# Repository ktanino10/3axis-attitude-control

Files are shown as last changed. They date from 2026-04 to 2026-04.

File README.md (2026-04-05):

# 🎲 3軸姿勢制御モジュール（Self-Balancing Cube）

> 🇬🇧 [English version here (README_en.md)](README_en.md)

リアクションホイールを用いた3軸姿勢制御モジュールの制作記録です。  
立方体が **角（頂点）で自立する** 倒立振子ロボットを、GitHub Copilot CLI を活用しながら設計・実装していきます。

## 🎯 プロジェクト概要

<div align="center">

**立方体が角で立つ？！**  
3つのリアクションホイールで Roll / Pitch / Yaw の3軸を制御し、  
不安定な頂点倒立を実現します。

</div>

## 📖 ドキュメント

| # | ドキュメント | 内容 |
|---|---|---|
| 1 | [理論解説](docs/01_theory.md) | なぜ角で立てるのか？数式による物理的説明 |
| 2 | [部品表（BOM）](docs/02_bom.md) | 必要な部品・購入先リスト |
| 3 | [回路図・配線](docs/03_circuit.md) | 回路図、ピン配線表 |
| 4 | [ソフトウェア環境](docs/04_software_setup.md) | Arduino IDE / Processing IDE セットアップ |
| 5 | [組立手順](docs/05_assembly.md) | 機械・電気の組立ガイド |
| 6 | [チューニング](docs/06_tuning.md) | PIDパラメータ調整方法 |
| 📅 | [実験スケジュール](docs/schedule.md) | 工程表・進捗管理 |
| 📝 | [実験ログ](experiments/log.md) | 日々の実験記録 |

## 🔧 ハードウェア構成

| コンポーネント | 型番・仕様 |
|---|---|
| マイコン | Raspberry Pi Pico W / ESP32 |
| IMU | MPU6050（6軸加速度・ジャイロ） |
| モーター | Nidec 24H055M020（ドライバ内蔵BLDC）×3 |
| リアクションホイール | 3Dプリント製 Φ116mm ×3 |
| バッテリー | LiPo 3S 11.1V |
| 筐体 | 3Dプリント製（PLA）□136mm |

## 📁 リポジトリ構成

```
├── docs/              # ドキュメント（理論・BOM・回路図・手順書）
├── firmware/          # マイコンファームウェア
│   ├── pico_w/       # Raspberry Pi Pico W 版
│   └── esp32/        # ESP32 版
├── processing/        # PIDチューニングGUI（Processing）
├── hardware/          # 回路図・ガーバーデータ
│   ├── gerber/
│   └── schematics/
└── experiments/       # 実験ログ
```

## 🙏 謝辞・参考

- [imo Lab.](https://garchiving.com/summary-of-self-balancing-cube/) — 設計の参考にさせていただきました
- [remrc/Self-Balancing-Cube](https://github.com/remrc/Self-Balancing-Cube)
- [willem-pennings/balancing-cube](https://github.com/willem-pennings/balancing-cube)
- 制作には [GitHub Copilot CLI](https://github.com/features/copilot) を活用しています

## 📄 ライセンス

MIT License

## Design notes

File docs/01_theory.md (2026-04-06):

# 🎲 3軸姿勢制御の物理理論

> なぜ立方体が角（頂点）で立てるのか？数式を用いた理論的解説

---

## 目次

1. [はじめに](#1-はじめに)
2. [このプロジェクトで使われる学問分野](#2-このプロジェクトで使われる学問分野)
3. [3次元倒立振子モデル](#3-3次元倒立振子モデル)
4. [リアクションホイールの原理](#4-リアクションホイールの原理)
5. [運動方程式の導出](#5-運動方程式の導出)
6. [座標系とキューブの幾何学](#6-座標系とキューブの幾何学)
7. [PID制御理論](#7-pid制御理論)
8. [モーターミキシング](#8-モーターミキシング)
9. [姿勢推定アルゴリズム](#9-姿勢推定アルゴリズム)
10. [安定条件の考察](#10-安定条件の考察)
11. [まとめ](#11-まとめ)

---

## 1. はじめに

立方体を角（頂点）の上に立てる — 直感的には不可能に思える。しかし、**リアクションホイール** と **フィードバック制御** を組み合わせれば、この不安定な平衡状態を維持できる。

本ドキュメントでは、この物理現象を数式で説明する。

### 1.1 本プロジェクトの物理的本質

角に立つ立方体は、本質的に **3次元倒立振子（3D Inverted Pendulum）** である。

- 🔴 **不安定平衡**: 重心が支点（角）の **真上** にあるとき、力学的には平衡状態だが、微小な擾乱で倒れ始める
- 🟢 **能動的安定化**: 3つのリアクションホイールが **角運動量の交換** によりトルクを発生させ、倒れを修正する
- 🔵 **フィードバック制御**: IMUセンサで傾きを検出し、PID制御で適切なモータートルクを計算する

### 1.2 身近な例で理解する

この原理は実は身近なところでも使われている:

| 身近な例 | 共通する原理 |
|---|---|
| **自転車に乗る人** | 傾きを感じたらハンドルを切って修正 → フィードバック制御 |
| **フィギュアスケートのスピン** | 腕を縮めると回転が速くなる → 角運動量保存則 |
| **人工衛星の姿勢制御** | リアクションホイールで向きを変える → 本プロジェクトと同じ原理！ |
| **セグウェイ** | 2輪で倒立する → 1軸の倒立振子 |

> 💡 実は人工衛星と同じ技術を手のひらサイズで実現するのがこのプロジェクトの面白さ。
> NASAの宇宙船もリアクションホイールで姿勢制御している。

### 1.3 なぜ「角」は特別なのか

通常の立方体の安定姿勢は **面** の上に置いた状態。角で立てることは物理的に可能だが、
**静的には不安定** である。

安定性の種類を整理すると:

```
安定平衡（面の上）     不安定平衡（角の上）     中立平衡（球）
     ___                    ●                      ○
    /   \                  / \                 ─────────
   /  ●  \               /   \
  / 谷底  \             / 山頂 \              どこでも平衡
```

- **安定平衡**: ボールが谷底にある状態。少し動かしても戻る
- **不安定平衡**: ボールが山頂にある状態。少し動かすと転がり落ちる ← **今回はここ！**
- **中立平衡**: 平面上のボール。動いたらその場にとどまる

角の上に立つ立方体は「山頂のボール」と同じ不安定平衡状態。
**常に能動的にバランスを取り続けなければ倒れる。**

---

## 2. このプロジェクトで使われる学問分野

このプロジェクトは一つの分野だけでは完成しない。
複数の学問が組み合わさった **メカトロニクス（ロボティクス）** の典型例である。

### 2.1 学問分野マップ

```
┌─────────────────────────────────────────────────────────────┐
│                  3軸姿勢制御モジュール                       │
│                                                             │
│  ┌──────────┐  ┌──────────┐  ┌──────────┐  ┌──────────┐   │
│  │ 物理学   │  │ 数学     │  │制御工学  │  │電気電子  │   │
│  │          │  │          │  │          │  │工学      │   │
│  │・古典力学│  │・線形代数│  │・PID制御 │  │・回路設計│   │
│  │・剛体力学│  │・微分方程│  │・状態空間│  │・モーター│   │
│  │・角運動量│  │  式      │  │  表現    │  │  制御    │   │
│  │  保存則  │  │・三角関数│  │・ディジタ│  │・センサ  │   │
│  │          │  │・テイラー│  │  ル信号  │  │  工学    │   │
│  │          │  │  展開    │  │  処理    │  │・PWM     │   │
│  └──────────┘  └──────────┘  └──────────┘  └──────────┘   │
│                                                             │
│  ┌──────────┐  ┌──────────┐  ┌──────────┐                  │
│  │ 情報工学 │  │ 機械工学 │  │通信工学  │                  │
│  │          │  │          │  │          │                  │
│  │・組込み  │  │・3D CAD  │  │・Bluetooth│                 │
│  │  プログラ│  │・3Dプリン│  │・シリアル│                  │
│  │  ミング  │  │  ト      │  │  通信    │                  │
│  │・I2C通信 │  │・機構設計│  │          │                  │
│  │・割り込み│  │・重心設計│  │          │                  │
│  └──────────┘  └──────────┘  └──────────┘                  │
└─────────────────────────────────────────────────────────────┘
```

### 2.2 各分野の詳細と本プロジェクトでの使われ方

#### 🔬 物理学（古典力学・剛体の力学）

最も基礎となる分野。「なぜ角で立てるのか」の答えそのもの。

| 物理法則 | 本プロジェクトでの使い方 | 登場する章 |
|---|---|---|
| **ニュートンの運動法則** | 回転版（$\tau = I\alpha$）で運動方程式を立てる | 第5章 |
| **角運動量保存則** | ホイールを加速→本体に逆トルク発生 | 第4章 |
| **重力トルク** | $mgl\sin\theta$ — 倒そうとする力 | 第5章 |
| **慣性モーメント** | $I = \frac{1}{6}ma^2$ — 回転のしにくさ | 第3章 |

> 📚 **学ぶなら**: 大学物理学（力学）、解析力学の教科書

#### 📐 数学

物理現象を定量的に扱うための道具。

| 数学の道具 | 何に使うか | 具体例 |
|---|---|---|
| **微分方程式** | 運動方程式の記述・解析 | $I\ddot{\theta} = mgl\theta - \tau$ |
| **線形代数** | ミキシング行列、状態空間表現 | 3×2のモーター分配行列 |
| **三角関数** | モーター配置の幾何学 | $\cos 30° = 0.866$ |
| **テイラー展開** | 小角近似 | $\sin\theta \approx \theta$ |
| **指数関数** | 不安定系の発散の記述 | $\theta(t) = \theta\_0 e^{\lambda t}$ |
| **atan2関数** | 加速度から角度を算出 | $\theta = \text{atan2}(a\_y, a\_z)$ |

> 📚 **学ぶなら**: 微分積分学、線形代数、工業数学

#### 🤖 制御工学

不安定な系を安定化させる理論。本プロジェクトの**要（かなめ）**。

| 制御理論 | 何をするか | ひとことで |
|---|---|---|
| **フィードバック制御** | センサで測定→計算→モーター駆動を繰り返す | 「測って→考えて→動く」のループ |
| **PID制御** | 偏差に対して比例・積分・微分の3つで修正 | 最も広く使われる基本制御器 |
| **安定性解析** | 系が発散しないか数学的に判定 | 固有値が正→不安定 |
| **離散化** | 連続系をデジタル（マイコン）で実装 | 10msごとにサンプリング |
| **相補フィルタ** | 2つのセンサの長所を組み合わせる | ジャイロ（速い）+ 加速度（正確） |

> 📚 **学ぶなら**: 制御工学入門、現代制御理論、ディジタル信号処理

#### ⚡ 電気・電子工学

理論を物理的に実現するためのハードウェア。

| 技術 | 役割 |
|---|---|
| **回路設計** | 電源回路（7805レギュレータ）、分圧回路（バッテリー電圧監視） |
| **PWM制御** | パルス幅変調でモーター速度を制御 |
| **I2C通信** | マイコンとIMUセンサ間のデジタル通信プロトコル |
| **ADC（A/D変換）** | アナログのバッテリー電圧をデジタル値に変換 |
| **PCB設計** | 回路基板の設計・ガーバーデータ作成・発注 |
| **MEMS センサ** | MPU6050 — 微小電気機械システムで加速度と角速度を検出 |

> 📚 **学ぶなら**: 電気回路、電子回路、センサ工学

#### 💻 情報工学（組込みプログラミング）

理論をソフトウェアとして実装する。

| 技術 | 内容 |
|---|---|
| **組込みC/C++** | Arduino フレームワークでマイコンプログラミング |
| **リアルタイム処理** | 10ms周期で確実にセンサ読取り→計算→モーター出力 |
| **割り込み処理** | エンコーダの回転パルスを取りこぼさず計数 |
| **固定小数点演算** | ビットシフト（`>> 4` = 1/16）で高速にフィルタ計算 |
| **Bluetooth SPP** | 無線でPIDパラメータをリアルタイム調整 |

> 📚 **学ぶなら**: マイコンプログラミング、リアルタイムOS、組込みシステム

#### 🔩 機械工学

物理的な構造体を設計・製造する。

| 技術 | 内容 |
|---|---|
| **3D CAD** | 筐体・ホイール・ブラケットの3次元設計 |
| **3Dプリント** | PLA樹脂でのパーツ造形（精度・強度の考慮） |
| **重心設計** | 点倒立時に重心がなるべく中央に来るよう配置 |
| **リアクションホイール設計** | 慣性モーメント（外周にボルトで重量調整） |
| **締結設計** | M3ボルト・ナットによる組立構造 |

> 📚 **学ぶなら**: 機械設計、3D CAD、材料力学

### 2.3 学問分野の関係図

```
        物理学（なぜ動くか）
            │
            ▼
        数学（定量的に記述）
            │
            ▼
      ┌─────┴─────┐
      ▼           ▼
  制御工学      電気電子工学
 （どう制御）   （回路で実現）
      │           │
      └─────┬─────┘
            ▼
        情報工学
     （プログラムで実装）
            │
            ▼
        機械工学
    （物理的な構造体）
            │
            ▼
      ★ 完成品 ★
  角で立つ立方体！
```

> 💡 **メカトロニクス** = Mechanics（機械）+ Electronics（電子）+ Informatics（情報）
> の造語。まさにこのプロジェクトそのもの。

---

## 3. 3次元倒立振子モデル

### 2.1 系の定義

立方体を角の上に置いた状態を考える。

```
        ↑ z (鉛直上向き)
        |
        ● 重心 (Center of Mass)
        |  ← 距離 l
        |
       ╱╲ 支点 (角)
──────╱──╲────── 地面
```

- **支点**: 立方体の1つの頂点（角）。地面と接触する点
- **重心**: 立方体の幾何学的中心
- **距離 l**: 支点から重心までの距離

### 2.2 幾何学的パラメータ

一辺の長さ $a$ の立方体について:

**支点から重心までの距離:**

$$l = \frac{\sqrt{3}}{2} a$$

立方体の対角線の長さは $\sqrt{3}a$ であり、角から中心まではその半分。

**立方体の慣性モーメント（重心まわり）:**

$$I_{body} = \frac{1}{6} m a^2$$

ここで $m$ は立方体の質量。（均質な立方体の場合、すべての主軸について同じ値）

### 2.3 自由体図

角に立つ立方体に作用する力とトルク:

```
            τ_wheel (リアクションホイールトルク)
               ↻
        ┌──────────┐
        │    ●     │← 重心: mg (重力, 下向き)
        │  / | \   │
        │ /  |  \  │
        └/───|───\─┘
        ╱    |    ╲
       ╱     ↓     ╲
      ●──── mg·l·sinθ ────→ 復元力（不安定方向！）
    支点
      ↑ N (垂直抗力)
```

**通常の振り子との決定的な違い:**
- 通常の振り子: 重力トルクが平衡位置に **戻す**（安定）
- 倒立振子: 重力トルクが平衡位置から **引き離す**（不安定）

---

## 3. リアクションホイールの原理

### 3.1 角運動量保存則

リアクションホイールの動作原理は **角運動量保存則** に基づく。

> 📝 **角運動量とは？**
> 回転している物体が持つ「回転の勢い」のこと。
> 質量 × 速度 = 運動量（直線運動）と同様に、
> 慣性モーメント × 角速度 = 角運動量（回転運動）。
> $L = I \cdot \omega$
>
> 角運動量保存則は「外からトルクを加えない限り、系全体の角運動量は変わらない」という法則。
> フィギュアスケーターが腕を縮めるとスピンが速くなるのも、この法則の表れ。

外力トルクが作用しない閉じた系において:

$$\vec{L}_{total} = \vec{L}_{body} + \vec{L}_{wheel} = \text{const}$$

ここで:
- $\vec{L}\_{total}$: 系全体の角運動量
- $\vec{L}\_{body}$: 立方体本体の角運動量
- $\vec{L}\_{wheel}$: リアクションホイールの角運動量

### 3.2 トルクの発生メカニズム

ホイールを**加速**すると、角運動量保存により本体は**逆方向に回転**する。

$$\vec{L}_{body} + \vec{L}_{wheel} = \text{const}$$

時間微分すると:

$$\dot{\vec{L}}_{body} + \dot{\vec{L}}_{wheel} = 0$$

$$\vec{\tau}_{body} = -\vec{\tau}_{wheel}$$

つまり:

$$I_{body} \cdot \dot{\omega}_{body} = -I_{wheel} \cdot \dot{\omega}_{wheel}$$

> **☝️ これが最も重要な式！**
> ホイールの角加速度 $\dot{\omega}\_{wheel}$ を制御することで、
> 本体にトルク $\tau\_{body}$ を与えられる。

### 3.3 直感的な理解

| ホイールの動作 | 本体への効果 |
|:---:|:---:|
| ホイール加速（↻速く） | 本体が逆回転（↺） |
| ホイール減速（↻遅く） | 本体が同方向に回転（↻） |
| ホイール一定速度 | 本体にトルクなし |

> 💡 **ポイント**: トルクを発生させるのはホイールの **回転速度の変化（角加速度）** であり、回転速度そのものではない。

> 📝 **人工衛星との共通点:**
> 国際宇宙ステーション（ISS）やハッブル宇宙望遠鏡も、宇宙空間での姿勢制御に
> リアクションホイールを使っている。宇宙では推進剤を使わずに向きを変えられるため、
> 非常に効率的な方法。本プロジェクトのキューブは、地上版のミニチュア人工衛星とも言える。

---

## 4. 運動方程式の導出

### 4.1 1軸の運動方程式

まず1軸（例えばRoll軸）について運動方程式を立てる。

角度 $\theta$ を鉛直からの傾きとすると:

$$I_{body} \ddot{\theta} = mgl \sin\theta - \tau_{wheel}$$

右辺の各項:
- $mgl\sin\theta$: 重力による不安定化トルク（倒れを加速する）
- $\tau\_{wheel} = I\_{wheel}\dot{\omega}\_{wheel}$: リアクションホイールによる制御トルク

> 📝 **この式の意味を直感的に理解する:**
> - 左辺 $I\_{body} \ddot{\theta}$ は「本体がどれだけ速く回転し始めるか」
> - 右辺第1項 $mgl\sin\theta$ は「重力が倒そうとする力」で、傾くほど大きくなる
> - 右辺第2項 $\tau\_{wheel}$ は「ホイールで発生させる制御力」で、これで重力に対抗する
>
> つまり **「ホイールの制御力 > 重力の倒す力」なら倒れない！**

### 4.2 小角近似による線形化

倒立状態（$\theta \approx 0$）付近では $\sin\theta \approx \theta$ と近似できる:

> 📝 **小角近似とは？**
> $\sin\theta$ は $\theta$ が小さいとき（10°以下程度）ほぼ $\theta$ と等しい。
> 例: $\sin(5°) = \sin(0.087\text{rad}) = 0.0872 \approx 0.087$
> この近似により、非線形の運動方程式が線形になり、解析が格段に簡単になる。

$$I_{body} \cdot \ddot{\theta} \approx mgl \cdot \theta - I_{wheel} \cdot \dot{\omega}_{wheel}$$

> **☝️ 線形化された運動方程式。** 左辺が本体の回転加速、右辺第1項が重力による転倒力、第2項が制御トルク。

これは **不安定な線形系** である。$\tau\_{wheel} = 0$ のとき:

$$\ddot{\theta} = \frac{mgl}{I_{body}} \theta$$

解は指数関数的に発散する:

$$\theta(t) = \theta_0 \cdot e^{\sqrt{mgl/I_{body}} \cdot t}$$

→ **制御なしでは必ず倒れる**（不安定平衡の数学的証明）

> 📝 **なぜ指数関数的に倒れるのか？**
> 上の式は「傾き $\theta$ が大きいほど、さらに傾く加速度 $\ddot{\theta}$ も大きくなる」
> という正のフィードバック（悪循環）を表している。
> $mgl/I\_{body}$ の値が大きいほど（重くて高い重心ほど）速く倒れる。

### 4.3 制御によるトルクの必要条件

倒立を維持するためには:

$$\tau_{wheel} \geq mgl\theta_{max}$$

ここで $\theta\_{max}$ はセンサが検出でき、制御が追いつく最大傾斜角。

**数値例（本プロジェクトのパラメータ）:**
- $m \approx 0.7$ kg（フレーム＋モーター＋バッテリー）
- $l \approx 0.118$ m（$a = 0.136$ m のとき $l = \sqrt{3}/2 \cdot 0.136$）
- $g = 9.81$ m/s²
- $\theta\_{max} = 7°= 0.122$ rad（コードの閾値より）

$$\tau_{min} = 0.7 \times 9.81 \times 0.118 \times 0.122 \approx 0.099 \text{ N·m}$$

→ 各モーターは少なくとも **約 0.1 N·m** のトルクを発生できる必要がある。

### 4.4 状態空間表現

状態ベクトル $\vec{x} = [\theta, \dot{\theta}]^T$、制御入力 $u = \tau\_{wheel}$ として:

$$\dot{\vec{x}} = \begin{bmatrix} 0 & 1 \\ \frac{mgl}{I_{body}} & 0 \end{bmatrix} \vec{x} + \begin{bmatrix} 0 \\ -\frac{1}{I_{body}} \end{bmatrix} u$$

固有値は $\lambda = \pm\sqrt{mgl/I\_{body}}$ で、正の実数固有値を持つため **開ループでは不安定**。

---

## 5. 座標系とキューブの幾何学

### 5.1 ボディフレームの定義

立方体が角で立った状態での座標系:

```
           ↑ Yaw軸 (z)
           |     （鉛直軸）
           |
    ──── Roll軸 (x)
         ╱
        ╱
  Pitch軸 (y)
```

- **Roll (x軸)**: 前後方向の傾き
- **Pitch (y軸)**: 左右方向の傾き  
- **Yaw (z軸)**: 鉛直軸まわりの回転

### 5.2 モーター配置の幾何学

3つのモーター（CTR, RH, LH）は立方体の3面に配置されている:

```
        上から見た図（点倒立時）

           CTR (Motor1)
            │  Roll軸方向
            │
            ● 重心
           ╱ ╲
          ╱   ╲
    LH ──╱ 60° ╲── RH
  (Motor3)       (Motor2)
```

- **CTR（Center）モーター**: Roll軸に対して**垂直**に配置
- **RH（Right Hand）モーター**: Roll軸から**30°**の位置
- **LH（Left Hand）モーター**: Roll軸から**-30°**の位置

### 5.3 三角比による分配

各モーターの回転軸が Roll/Pitch 軸に対してなす角度から:

| モーター | Roll成分 | Pitch成分 |
|---|---|---|
| CTR | $\cos(0°) = 1$ | $\cos(90°) = 0$ |
| RH | $\cos(60°) = 0.5$ | $\cos(30°) = 0.866$ |
| LH | $-\cos(60°) = -0.5$ | $\cos(30°) = 0.866$ |

---

## 6. PID制御理論

### 6.1 基本的なPID制御

PID制御器は、偏差 $e(t)$ に基づいて制御入力 $u(t)$ を計算する:

$$u(t) = K_p \cdot e(t) + K_i \int_0^t e(\tau) d\tau + K_d \frac{de(t)}{dt}$$

各項の役割:
- **P（比例）項**: 現在の偏差に比例した修正力 → 応答速度
- **I（積分）項**: 過去の偏差の累積を修正 → 定常偏差の除去
- **D（微分）項**: 偏差の変化率に基づく制動力 → 振動の抑制

> 📝 **PIDを車の運転で例えると:**
>
> 目的地まで車を走らせるとき:
> - **P（比例）**: 「目的地まで遠い → アクセルを強く踏む」。ズレが大きいほど強く修正
> - **I（積分）**: 「ずっと少し右にズレている → ハンドルを少し左に切り続ける」。蓄積した誤差を修正
> - **D（微分）**: 「急にカーブに差し掛かった → 早めにブレーキ」。変化の速さに応じて予測的に修正
>
> PIDの3つを組み合わせることで、「速く」「正確に」「振動なく」目標に到達できる。

### 6.2 角速度PID（本プロジェクトの実装）

本プロジェクトでは、直接角度をPID制御するのではなく、**角速度をPID制御**している。

> 📝 **なぜ角度ではなく角速度を制御するのか？**
> 角度を直接PID制御すると、微分項 D が「角度の変化率」＝角速度になる。
> しかしジャイロセンサが直接出力するのが角速度なので、これをそのまま使う方が
> ノイズが少なく、チューニングもしやすい。imo Lab.の設計でもこの方式が採用されている。

**ステップ1: 目標角度の自動補正**

$$\theta_{target}(t+\Delta t) = \theta_{target}(t) + K_t \cdot \Delta t \cdot (\theta_{target}(t) - \theta(t))$$

> 📝 組立てたキューブは完璧に対称ではないため、センサーの0°と実際のバランス点が
> ズレている。この式はそのズレを自動で学習・補正する仕組み。 $K\_t$ が大きいほど速く補正する。

**ステップ2: 目標角速度の計算**

$$\omega_{target} = K_a \cdot (\theta_{target} - \theta)$$

角度偏差から目標となる角速度を求める。

**ステップ3: 角速度PID制御**

$$P = \omega_{target} - \omega_{gyro}$$

$$I = \theta \quad \text{（角度そのものを積分項として使用）}$$

$$D = \omega_{gyro}(t) - \omega_{gyro}(t-1) \quad \text{（微分先行型）}$$

$$u = K_p \cdot P + K_i \cdot I - K_d \cdot D$$

> 📝 **微分先行型とは？**
> 通常のD項は「偏差の変化率」だが、ここでは「ジャイロ角速度の変化率」を使っている。
> これは目標値が急に変わった時の急激な出力変化（微分キック）を防ぐテクニック。

### 6.3 離散化（デジタル実装）

マイコンでの実装は離散時間系:

$$P_k = \omega_{target,k} - \omega_{gyro,k}$$

$$I_k = I_{k-1} + P_k \cdot \Delta t$$

$$D_k = \omega_{gyro,k} - \omega_{gyro,k-1}$$

$$u_k = K_p \cdot P_k + K_i \cdot I_k - K_d \cdot D_k$$

制御周期: $\Delta t = 10$ ms（100 Hz）— コード上の `if (currentTime - loopTimer >= 10000)` より。

### 6.4 PIDパラメータの初期値

コードから抽出した初期値:

| パラメータ | 1号機（ESP32） | 2号機（Pico） | 役割 |
|---|:---:|:---:|---|
| $K\_t$ (Ks) | 1.0 | 1.3 | 目標角度補正速度 |
| $K\_a$ (Kp_angle) | 5.0 | 5.5 | 角度→角速度変換ゲイン |
| $K\_p$ | 60.0 | 32.0 | 比例ゲイン |
| $K\_i$ | 12.0 | 45.0 | 積分ゲイン |
| $K\_d$ | 90.0 | 95.0 | 微分ゲイン |

---

## 7. モーターミキシング

### 7.1 ミキシング行列

Roll/Pitch の PID出力を3つのモーターに分配する:

$$\begin{bmatrix} u_{CTR} \\ u_{RH} \\ u_{LH} \end{bmatrix} = \begin{bmatrix} 1 & 0 \\ 0.5 & 0.866 \\ -0.5 & 0.866 \end{bmatrix} \begin{bmatrix} PID_{Roll} \\ PID_{Pitch} \end{bmatrix}$$

展開すると:

$$u_{CTR} = PID_{Roll}$$

$$u_{RH} = 0.5 \cdot PID_{Roll} + 0.866 \cdot PID_{Pitch}$$

$$u_{LH} = -0.5 \cdot PID_{Roll} + 0.866 \cdot PID_{Pitch}$$

### 7.2 幾何学的導出

なぜ $0.866$ と $0.5$ なのか？

3つのモーターは、点倒立時に上から見ると **120°間隔** で配置されている:

```
            0° (CTR)
            │
     240°───●───120°
     (LH)       (RH)
```

Roll軸（0°方向）に対する各モーターの寄与:

$$\text{Roll成分} = \cos(\alpha)$$
$$\text{Pitch成分} = \sin(\alpha)$$

| モーター | 角度 α | cos(α) | sin(α) |
|---|:---:|:---:|:---:|
| CTR | 0° | 1.0 | 0.0 |
| RH | 120° → **Roll: cos60°, Pitch: cos30°** | 0.5 | 0.866 |
| LH | 240° → **Roll: -cos60°, Pitch: cos30°** | -0.5 | 0.866 |

### 7.3 Yaw軸制御（2号機のみ）

2号機では Yaw（z軸回転）制御も追加:

$$u_{CTR} = PID_{Roll} + PID_{Yaw}$$

$$u_{RH} = 0.5 \cdot PID_{Roll} + 0.866 \cdot PID_{Pitch} - PID_{Yaw}$$

$$u_{LH} = -0.5 \cdot PID_{Roll} + 0.866 \cdot PID_{Pitch} + PID_{Yaw}$$

Yaw制御は3つのホイールすべてに **同方向** のトルクを加えることで実現する。

---

## 8. 姿勢推定アルゴリズム

### 8.1 問題設定

MPU6050は2種類のセンサを持つ:

| センサ | 測定値 | 長所 | 短所 |
|---|---|---|---|
| 加速度計 | 重力方向 → 角度 | ドリフトなし | 振動・加速に弱い |
| ジャイロスコープ | 角速度 → 角度（積分） | 高速応答 | ドリフトする |

> 📝 **なぜ1つのセンサではダメなのか？**
>
> - **加速度計だけ**: 重力の方向から傾きがわかるが、モーターの振動で値がブレブレになる。
>   また、ホイールの回転で遠心力が加わると重力と区別できない。
>
> - **ジャイロだけ**: 角速度を積分すれば角度が求まるが、微小な誤差が蓄積し続ける（ドリフト）。
>   30秒もすると実際とは全く違う角度を示すようになる。
>
> → **両方を組み合わせて互いの弱点を補う** のが相補フィルタの考え方。

### 8.2 相補フィルタ

本プロジェクトでは **相補フィルタ** で両者を融合している:

$$\theta_{est} = \alpha \cdot (\theta_{prev} + \omega_{gyro} \cdot \Delta t) + (1 - \alpha) \cdot \theta_{acc}$$

- $\alpha$: フィルタ係数（0.9〜0.99、ジャイロ寄り）
- $\omega\_{gyro} \cdot \Delta t$: ジャイロの角速度を積分した角度変化
- $\theta\_{acc}$: 加速度計から計算した角度

> 📝 **相補フィルタを直感的に理解する:**
>
> ```
> 短期的（高周波）→ ジャイロを信頼（振動に強い、ドリフト前なら正確）
> 長期的（低周波）→ 加速度を信頼（ドリフトしない、真の重力方向がわかる）
> ```
>
> $\alpha = 0.94$ なら「94%はジャイロを信頼し、6%は加速度計で補正する」という意味。
> 短い時間ではジャイロ主体で素早く反応し、長い時間では加速度計でドリフトを修正する。

### 8.3 実装上のアルゴリズム（コード解析）

実際のコードでは、相補フィルタを **重力ベクトル推定** として実装している:

**ステップ1: ジャイロによる重力ベクトル回転**

$$\vec{V}_g' = \vec{V}_g + \vec{\omega} \times \vec{V}_g \cdot \Delta t$$

ジャイロの角速度で重力ベクトルの方向を更新（回転行列の1次近似）。

> 📝 外積 $\vec{\omega} \times \vec{V}\_g$ は「角速度ベクトル $\omega$ によって
> 重力ベクトル $V\_g$ がどの方向に回転するか」を計算している。

**ステップ2: 加速度計による補正（ローパスフィルタ）**

$$\vec{V}_g = \vec{V}_g' + \frac{1}{16}(\vec{a}_{LPF} - \vec{V}_g')$$

加速度計の値でドリフトを補正。$1/16$ はビットシフト `>> 4` に対応。

> 📝 $\frac{1}{16}$ は相補フィルタの $1 - \alpha$ に相当。
> つまり $\alpha = 15/16 = 0.9375$（約94%ジャイロ信頼）。
> ビットシフトを使うことでマイコン上で高速に計算できる。

**ステップ3: 角度の算出**

$$\theta_{Roll} = \text{atan2}(V_{g,y}, V_{g,z})$$

$$\theta_{Pitch} = -\text{atan2}(V_{g,x}, \sqrt{V_{g,y}^2 + V_{g,z}^2})$$

$$\theta_{Yaw} += -\omega_z \cdot \Delta t \quad \text{（ジャイロ積分のみ）}$$

> ⚠️ Yaw角はジャイロ積分のみのため、長時間でドリフトする。

---

## 9. 安定条件の考察

### 9.1 制御可能性

倒立を維持するための条件:

1. **十分なトルク**: $\tau\_{max} > mgl\theta\_{max}$
2. **十分な応答速度**: 制御周期 $\Delta t$ が系の時定数より十分短い
3. **正確な姿勢推定**: IMUの精度と相補フィルタの帯域

### 9.2 系の時定数

線形化モデルの固有値から、倒れの時定数:

$$T = \frac{1}{\sqrt{mgl/I_{body}}}$$

本プロジェクトの値（$m = 0.7$ kg, $l = 0.118$ m, $I\_{body} = ma^2/6$）:

$$I_{body} = \frac{0.7 \times 0.136^2}{6} = 0.00216 \text{ kg·m}^2$$

$$T = \frac{1}{\sqrt{\frac{0.7 \times 9.81 \times 0.118}{0.00216}}} = \frac{1}{\sqrt{375}} \approx 0.052 \text{ s} \approx 52 \text{ ms}$$

→ 制御周期 10ms（100Hz）は、時定数 52ms より十分短い ✅

### 9.3 なぜ角で立てるのか — まとめ

角で立てる理由を一言で:

> **リアクションホイールの角加速度による反作用トルクが、重力による転倒トルクを上回り、かつ十分高速なフィードバック制御で修正し続けるから。**

数式で:

$$\underbrace{I_{wheel}\dot{\omega}_{wheel}}_{\text{制御トルク}} > \underbrace{mgl\sin\theta}_{\text{転倒トルク}} \quad \text{かつ} \quad \underbrace{\Delta t}_{\text{制御周期}} \ll \underbrace{T}_{\text{系の時定数}}$$

---

## 10. まとめ

| 物理的要素 | 数式 | 本プロジェクトでの実装 |
|---|---|---|
| 角運動量保存 | $L\_{body} + L\_{wheel} = \text{const}$ | リアクションホイール3個 |
| 運動方程式 | $I\ddot{\theta} = mgl\theta - \tau\_{wheel}$ | PID制御で $\tau\_{wheel}$ を制御 |
| PID制御 | $u = K\_p P + K\_i I - K\_d D$ | 角速度PID（imo Lab.方式） |
| モーターミキシング | cos30°/cos60° 分配行列 | 3モーターの120°配置 |
| 姿勢推定 | 相補フィルタ（重力ベクトル法） | MPU6050（加速度+ジャイロ） |
| 安定条件 | $\tau\_{max} > mgl\theta$, $\Delta t \ll T$ | 100Hz制御、時定数52ms |

---

## 参考文献

1. imo Lab. "[3軸姿勢制御モジュールの姿勢制御方法](https://garchiving.com/how-to-3axis-control-self-balancing-cube/)"
2. remrc. "[Self-Balancing-Cube](https://github.com/remrc/Self-Balancing-Cube)" GitHub
3. willem-pennings. "[balancing-cube](https://github.com/willem-pennings/balancing-cube)" GitHub
4. 古典力学テキスト — オイラーの回転方程式、剛体の力学

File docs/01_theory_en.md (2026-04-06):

# 🎲 Physics of 3-Axis Attitude Control

> Why can a cube balance on its corner? A theoretical explanation with equations

---

## Table of Contents

1. [Introduction](#1-introduction)
2. [Academic Disciplines Used in This Project](#2-academic-disciplines-used-in-this-project)
3. [3D Inverted Pendulum Model](#3-3d-inverted-pendulum-model)
4. [Reaction Wheel Principle](#4-reaction-wheel-principle)
5. [Deriving the Equations of Motion](#5-deriving-the-equations-of-motion)
6. [Coordinate System and Cube Geometry](#6-coordinate-system-and-cube-geometry)
7. [PID Control Theory](#7-pid-control-theory)
8. [Motor Mixing](#8-motor-mixing)
9. [Attitude Estimation Algorithm](#9-attitude-estimation-algorithm)
10. [Stability Condition Analysis](#10-stability-condition-analysis)
11. [Summary](#11-summary)

---

## 1. Introduction

Balancing a cube on its corner — intuitively, it seems impossible. However, by combining **reaction wheels** with **feedback control**, this unstable equilibrium can be maintained.

This document explains the underlying physics using equations.

### 1.1 The Physical Essence of This Project

A cube balanced on its corner is essentially a **3D Inverted Pendulum**.

- 🔴 **Unstable equilibrium**: When the center of gravity is **directly above** the pivot point (corner), the system is in mechanical equilibrium, but any tiny disturbance will cause it to topple
- 🟢 **Active stabilization**: Three reaction wheels generate torque through **exchange of angular momentum**, correcting any tilt
- 🔵 **Feedback control**: An IMU sensor detects tilt, and PID control computes the appropriate motor torque

### 1.2 Understanding Through Everyday Examples

This principle is actually used in many familiar situations:

| Everyday Example | Shared Principle |
|---|---|
| **Riding a bicycle** | Feel a tilt → turn the handlebars to correct → feedback control |
| **Figure skating spin** | Pull arms in → spin faster → conservation of angular momentum |
| **Satellite attitude control** | Change orientation using reaction wheels → same principle as this project! |
| **Segway** | Balances on 2 wheels → single-axis inverted pendulum |

> 💡 The fun of this project is realizing satellite-grade technology at palm size.
> NASA spacecraft also use reaction wheels for attitude control.

### 1.3 Why Is the "Corner" Special?

A cube's normal stable resting position is on a **face**. Balancing on a corner is physically possible, but
**statically unstable**.

The types of equilibrium can be organized as follows:

```
安定平衡（面の上）     不安定平衡（角の上）     中立平衡（球）
     ___                    ●                      ○
    /   \                  / \                 ─────────
   /  ●  \               /   \
  / 谷底  \             / 山頂 \              どこでも平衡
```

- **Stable equilibrium**: A ball at the bottom of a valley. Push it slightly and it rolls back
- **Unstable equilibrium**: A ball on a hilltop. Push it slightly and it rolls away ← **This is our case!**
- **Neutral equilibrium**: A ball on a flat surface. Push it and it stays wherever it stops

A cube balanced on its corner is in the same unstable equilibrium as a "ball on a hilltop."
**It will topple unless actively balanced at all times.**

---

## 2. Academic Disciplines Used in This Project

This project cannot be completed with a single discipline alone.
It is a textbook example of **mechatronics (robotics)**, combining multiple fields of study.

### 2.1 Discipline Map

```
┌─────────────────────────────────────────────────────────────┐
│                  3軸姿勢制御モジュール                       │
│                                                             │
│  ┌──────────┐  ┌──────────┐  ┌──────────┐  ┌──────────┐   │
│  │ 物理学   │  │ 数学     │  │制御工学  │  │電気電子  │   │
│  │          │  │          │  │          │  │工学      │   │
│  │・古典力学│  │・線形代数│  │・PID制御 │  │・回路設計│   │
│  │・剛体力学│  │・微分方程│  │・状態空間│  │・モーター│   │
│  │・角運動量│  │  式      │  │  表現    │  │  制御    │   │
│  │  保存則  │  │・三角関数│  │・ディジタ│  │・センサ  │   │
│  │          │  │・テイラー│  │  ル信号  │  │  工学    │   │
│  │          │  │  展開    │  │  処理    │  │・PWM     │   │
│  └──────────┘  └──────────┘  └──────────┘  └──────────┘   │
│                                                             │
│  ┌──────────┐  ┌──────────┐  ┌──────────┐                  │
│  │ 情報工学 │  │ 機械工学 │  │通信工学  │                  │
│  │          │  │          │  │          │                  │
│  │・組込み  │  │・3D CAD  │  │・Bluetooth│                 │
│  │  プログラ│  │・3Dプリン│  │・シリアル│                  │
│  │  ミング  │  │  ト      │  │  通信    │                  │
│  │・I2C通信 │  │・機構設計│  │          │                  │
│  │・割り込み│  │・重心設計│  │          │                  │
│  └──────────┘  └──────────┘  └──────────┘                  │
└─────────────────────────────────────────────────────────────┘
```

### 2.2 Details of Each Discipline and How It's Used in This Project

#### 🔬 Physics (Classical Mechanics / Rigid Body Dynamics)

The most fundamental discipline. It directly answers "why can it balance on a corner?"

| Physical Law | How It's Used in This Project | Chapter |
|---|---|---|
| **Newton's laws of motion** | Rotational form ($\tau = I\alpha$) to derive equations of motion | Chapter 5 |
| **Conservation of angular momentum** | Accelerate a wheel → generates reaction torque on the body | Chapter 4 |
| **Gravitational torque** | $mgl\sin\theta$ — the force trying to topple it | Chapter 5 |
| **Moment of inertia** | $I = \frac{1}{6}ma^2$ — resistance to rotational acceleration | Chapter 3 |

> 📚 **To learn more**: University-level physics (mechanics), analytical mechanics textbooks

#### 📐 Mathematics

The tools for describing physical phenomena quantitatively.

| Mathematical Tool | What It's Used For | Specific Example |
|---|---|---|
| **Differential equations** | Describing and analyzing equations of motion | $I\ddot{\theta} = mgl\theta - \tau$ |
| **Linear algebra** | Mixing matrix, state-space representation | 3×2 motor distribution matrix |
| **Trigonometry** | Geometry of motor placement | $\cos 30° = 0.866$ |
| **Taylor expansion** | Small-angle approximation | $\sin\theta \approx \theta$ |
| **Exponential functions** | Describing divergence of unstable systems | $\theta(t) = \theta\_0 e^{\lambda t}$ |
| **atan2 function** | Computing angle from acceleration | $\theta = \text{atan2}(a\_y, a\_z)$ |

> 📚 **To learn more**: Calculus, linear algebra, engineering mathematics

#### 🤖 Control Engineering

The theory of stabilizing unstable systems. The **cornerstone** of this project.

| Control Theory | What It Does | In One Phrase |
|---|---|---|
| **Feedback control** | Repeated cycle of sensor → compute → drive motor | "Measure → Think → Act" loop |
| **PID control** | Corrects error using proportional, integral, and derivative terms | The most widely used basic controller |
| **Stability analysis** | Mathematically determines whether a system will diverge | Positive eigenvalue → unstable |
| **Discretization** | Implementing continuous systems on digital (microcontroller) hardware | Sampling every 10 ms |
| **Complementary filter** | Combines the strengths of two different sensors | Gyro (fast) + Accelerometer (accurate) |

> 📚 **To learn more**: Introduction to control engineering, modern control theory, digital signal processing

#### ⚡ Electrical and Electronic Engineering

The hardware that physically realizes the theory.

| Technology | Role |
|---|---|
| **Circuit design** | Power supply circuit (7805 regulator), voltage divider (battery voltage monitoring) |
| **PWM control** | Controlling motor speed via pulse-width modulation |
| **I2C communication** | Digital communication protocol between microcontroller and IMU sensor |
| **ADC (Analog-to-Digital Conversion)** | Converting analog battery voltage to a digital value |
| **PCB design** | Designing circuit boards, generating Gerber data, ordering fabrication |
| **MEMS sensors** | MPU6050 — Micro-Electro-Mechanical System detecting acceleration and angular velocity |

> 📚 **To learn more**: Electric circuits, electronic circuits, sensor engineering

#### 💻 Computer Science (Embedded Programming)

Implementing the theory as software.

| Technology | Description |
|---|---|
| **Embedded C/C++** | Microcontroller programming using the Arduino framework |
| **Real-time processing** | Reliably reading sensors → computing → driving motors on a 10 ms cycle |
| **Interrupt handling** | Counting encoder rotation pulses without missing any |
| **Fixed-point arithmetic** | High-speed filter computation using bit shifts (`>> 4` = 1/16) |
| **Bluetooth SPP** | Wireless real-time tuning of PID parameters |

> 📚 **To learn more**: Microcontroller programming, real-time OS, embedded systems

#### 🔩 Mechanical Engineering

Designing and manufacturing the physical structure.

| Technology | Description |
|---|---|
| **3D CAD** | 3D design of the enclosure, wheels, and brackets |
| **3D printing** | Fabricating parts in PLA plastic (considering precision and strength) |
| **Center-of-gravity design** | Arranging components so the center of gravity is as centered as possible when corner-standing |
| **Reaction wheel design** | Adjusting moment of inertia (adding bolts around the rim for weight tuning) |
| **Fastener design** | Assembly structure using M3 bolts and nuts |

> 📚 **To learn more**: Mechanical design, 3D CAD, strength of materials

### 2.3 How the Disciplines Relate

```
        物理学（なぜ動くか）
            │
            ▼
        数学（定量的に記述）
            │
            ▼
      ┌─────┴─────┐
      ▼           ▼
  制御工学      電気電子工学
 （どう制御）   （回路で実現）
      │           │
      └─────┬─────┘
            ▼
        情報工学
     （プログラムで実装）
            │
            ▼
        機械工学
    （物理的な構造体）
            │
            ▼
      ★ 完成品 ★
  角で立つ立方体！
```

> 💡 **Mechatronics** = Mechanics + Electronics + Informatics —
> a coined term. This project is a perfect embodiment of it.

---

## 3. 3D Inverted Pendulum Model

### 2.1 System Definition

Consider a cube placed on one of its corners.

```
        ↑ z (鉛直上向き)
        |
        ● 重心 (Center of Mass)
        |  ← 距離 l
        |
       ╱╲ 支点 (角)
──────╱──╲────── 地面
```

- **Pivot point**: One vertex (corner) of the cube. The point of contact with the ground
- **Center of mass**: The geometric center of the cube
- **Distance l**: The distance from the pivot to the center of mass

### 2.2 Geometric Parameters

For a cube with edge length $a$:

**Distance from pivot to center of mass:**

$$l = \frac{\sqrt{3}}{2} a$$

The space diagonal of a cube is $\sqrt{3}a$, and the distance from a corner to the center is half of that.

**Moment of inertia of the cube (about the center of mass):**

$$I_{body} = \frac{1}{6} m a^2$$

where $m$ is the mass of the cube. (For a uniform cube, this value is the same about all principal axes.)

### 2.3 Free Body Diagram

Forces and torques acting on a cube balanced on its corner:

```
            τ_wheel (リアクションホイールトルク)
               ↻
        ┌──────────┐
        │    ●     │← 重心: mg (重力, 下向き)
        │  / | \   │
        │ /  |  \  │
        └/───|───\─┘
        ╱    |    ╲
       ╱     ↓     ╲
      ●──── mg·l·sinθ ────→ 復元力（不安定方向！）
    支点
      ↑ N (垂直抗力)
```

**The crucial difference from a regular pendulum:**
- Regular pendulum: gravitational torque **restores** the system to equilibrium (stable)
- Inverted pendulum: gravitational torque **drives** the system away from equilibrium (unstable)

---

## 3. Reaction Wheel Principle

### 3.1 Conservation of Angular Momentum

The operating principle of reaction wheels is based on the **conservation of angular momentum**.

> 📝 **What is angular momentum?**
> It is the "rotational momentum" of a spinning object.
> Just as mass × velocity = linear momentum (for translational motion),
> moment of inertia × angular velocity = angular momentum (for rotational motion).
> $L = I \cdot \omega$
>
> The conservation of angular momentum states: "Unless an external torque is applied, the total angular momentum of a system remains constant."
> This is the same law that explains why a figure skater spins faster when pulling their arms in.

In a closed system with no external torque:

$$\vec{L}_{total} = \vec{L}_{body} + \vec{L}_{wheel} = \text{const}$$

where:
- $\vec{L}\_{total}$: Total angular momentum of the system
- $\vec{L}\_{body}$: Angular momentum of the cube body
- $\vec{L}\_{wheel}$: Angular momentum of the reaction wheel

### 3.2 Torque Generation Mechanism

When a wheel is **accelerated**, conservation of angular momentum causes the body to **rotate in the opposite direction**.

$$\vec{L}_{body} + \vec{L}_{wheel} = \text{const}$$

Taking the time derivative:

$$\dot{\vec{L}}_{body} + \dot{\vec{L}}_{wheel} = 0$$

$$\vec{\tau}_{body} = -\vec{\tau}_{wheel}$$

That is:

$$I_{body} \cdot \dot{\omega}_{body} = -I_{wheel} \cdot \dot{\omega}_{wheel}$$

> **☝️ This is the most important equation!**
> By controlling the wheel's angular acceleration $\dot{\omega}\_{wheel}$,
> we can apply a torque $\tau\_{body}$ to the body.

### 3.3 Intuitive Understanding

| Wheel Action | Effect on Body |
|:---:|:---:|
| Wheel accelerates (↻ faster) | Body rotates in reverse (↺) |
| Wheel decelerates (↻ slower) | Body rotates in the same direction (↻) |
| Wheel at constant speed | No torque on the body |

> 💡 **Key point**: What generates torque is the **change in rotational speed (angular acceleration)** of the wheel, not the rotational speed itself.

> 📝 **Similarities with spacecraft:**
> The International Space Station (ISS) and the Hubble Space Telescope also use
> reaction wheels for attitude control in space. In space, this is an extremely efficient
> method since orientation can be changed without consuming propellant. This project's cube
> is essentially a terrestrial miniature satellite.

---

## 4. Deriving the Equations of Motion

### 4.1 Single-Axis Equation of Motion

First, let's derive the equation of motion for a single axis (e.g., the Roll axis).

Let $\theta$ be the tilt angle from the vertical:

$$I_{body} \ddot{\theta} = mgl \sin\theta - \tau_{wheel}$$

Each term on the right-hand side:
- $mgl\sin\theta$: Destabilizing gravitational torque (accelerates the tilt)
- $\tau\_{wheel} = I\_{wheel}\dot{\omega}\_{wheel}$: Control torque from the reaction wheel

> 📝 **Understanding this equation intuitively:**
> - Left side $I\_{body} \ddot{\theta}$: "How quickly the body starts to rotate"
> - Right-side 1st term $mgl\sin\theta$: "The force of gravity trying to topple it" — grows larger with greater tilt
> - Right-side 2nd term $\tau\_{wheel}$: "The control force generated by the wheel" — used to counteract gravity
>
> In other words, **if the wheel's control force > gravity's toppling force, it won't fall!**

### 4.2 Linearization via Small-Angle Approximation

Near the upright position ($\theta \approx 0$), we can approximate $\sin\theta \approx \theta$:

> 📝 **What is the small-angle approximation?**
> When $\theta$ is small (roughly below 10°), $\sin\theta$ is approximately equal to $\theta$.
> Example: $\sin(5°) = \sin(0.087\text{rad}) = 0.0872 \approx 0.087$
> This approximation turns the nonlinear equation of motion into a linear one, making analysis much simpler.

$$I_{body} \cdot \ddot{\theta} \approx mgl \cdot \theta - I_{wheel} \cdot \dot{\omega}_{wheel}$$

> **☝️ The linearized equation of motion.** The left side is the body's rotational acceleration; the 1st term on the right is the gravitational toppling force; the 2nd term is the control torque.

This is an **unstable linear system**. When $\tau\_{wheel} = 0$:

$$\ddot{\theta} = \frac{mgl}{I_{body}} \theta$$

The solution diverges exponentially:

$$\theta(t) = \theta_0 \cdot e^{\sqrt{mgl/I_{body}} \cdot t}$$

→ **Without control, it will inevitably topple** (mathematical proof of unstable equilibrium)

> 📝 **Why does it topple exponentially?**
> The equation above says "the greater the tilt $\theta$, the greater the angular acceleration $\ddot{\theta}$ that increases the tilt further."
> This is positive feedback (a vicious cycle).
> The larger $mgl/I\_{body}$ is (heavier and higher center of gravity), the faster it falls.

### 4.3 Required Torque for Maintaining Balance

To maintain the inverted position:

$$\tau_{wheel} \geq mgl\theta_{max}$$

where $\theta\_{max}$ is the maximum tilt angle the sensor can detect and the controller can correct in time.

**Numerical example (this project's parameters):**
- $m \approx 0.7$ kg (frame + motors + battery)
- $l \approx 0.118$ m (for $a = 0.136$ m: $l = \sqrt{3}/2 \cdot 0.136$)
- $g = 9.81$ m/s²
- $\theta\_{max} = 7°= 0.122$ rad (from the code's threshold)

$$\tau_{min} = 0.7 \times 9.81 \times 0.118 \times 0.122 \approx 0.099 \text{ N·m}$$

→ Each motor must be capable of producing at least **approximately 0.1 N·m** of torque.

### 4.4 State-Space Representation

With state vector $\vec{x} = [\theta, \dot{\theta}]^T$ and control input $u = \tau\_{wheel}$:

$$\dot{\vec{x}} = \begin{bmatrix} 0 & 1 \\ \frac{mgl}{I_{body}} & 0 \end{bmatrix} \vec{x} + \begin{bmatrix} 0 \\ -\frac{1}{I_{body}} \end{bmatrix} u$$

The eigenvalues are $\lambda = \pm\sqrt{mgl/I\_{body}}$. Since there is a positive real eigenvalue, the system is **unstable in open loop**.

---

## 5. Coordinate System and Cube Geometry

### 5.1 Body Frame Definition

The coordinate system when the cube is balanced on its corner:

```
           ↑ Yaw軸 (z)
           |     （鉛直軸）
           |
    ──── Roll軸 (x)
         ╱
        ╱
  Pitch軸 (y)
```

- **Roll (x-axis)**: Tilt in the fore–aft direction
- **Pitch (y-axis)**: Tilt in the left–right direction
- **Yaw (z-axis)**: Rotation about the vertical axis

### 5.2 Motor Placement Geometry

Three motors (CTR, RH, LH) are mounted on three faces of the cube:

```
        上から見た図（点倒立時）

           CTR (Motor1)
            │  Roll軸方向
            │
            ● 重心
           ╱ ╲
          ╱   ╲
    LH ──╱ 60° ╲── RH
  (Motor3)       (Motor2)
```

- **CTR (Center) motor**: Mounted **perpendicular** to the Roll axis
- **RH (Right Hand) motor**: Positioned at **30°** from the Roll axis
- **LH (Left Hand) motor**: Positioned at **−30°** from the Roll axis

### 5.3 Trigonometric Distribution

From the angle each motor's rotation axis makes with the Roll/Pitch axes:

| Motor | Roll Component | Pitch Component |
|---|---|---|
| CTR | $\cos(0°) = 1$ | $\cos(90°) = 0$ |
| RH | $\cos(60°) = 0.5$ | $\cos(30°) = 0.866$ |
| LH | $-\cos(60°) = -0.5$ | $\cos(30°) = 0.866$ |

---

## 6. PID Control Theory

### 6.1 Basic PID Control

A PID controller computes the control input $u(t)$ based on the error $e(t)$:

$$u(t) = K_p \cdot e(t) + K_i \int_0^t e(\tau) d\tau + K_d \frac{de(t)}{dt}$$

Role of each term:
- **P (Proportional) term**: Correction force proportional to the current error → response speed
- **I (Integral) term**: Corrects accumulated past errors → eliminates steady-state error
- **D (Derivative) term**: Damping force based on the rate of change of error → suppresses oscillation

> 📝 **PID explained with a driving analogy:**
>
> Imagine driving a car to a destination:
> - **P (Proportional)**: "Far from the destination → press the gas harder." The larger the deviation, the stronger the correction
> - **I (Integral)**: "I've been drifting slightly right for a while → keep steering slightly left." Corrects accumulated error
> - **D (Derivative)**: "A sharp curve is coming up → brake early." Predictive correction based on the rate of change
>
> By combining all three PID terms, you can reach the target "quickly," "accurately," and "without oscillation."

### 6.2 Angular Velocity PID (This Project's Implementation)

In this project, rather than directly PID-controlling the angle, we PID-control the **angular velocity**.

> 📝 **Why control angular velocity instead of angle?**
> If you PID-control the angle directly, the derivative term D becomes the "rate of change of angle" = angular velocity.
> Since the gyro sensor directly outputs angular velocity, using it as-is results in less noise
> and easier tuning. The imo Lab. design also adopts this approach.

**Step 1: Automatic target angle correction**

$$\theta_{target}(t+\Delta t) = \theta_{target}(t) + K_t \cdot \Delta t \cdot (\theta_{target}(t) - \theta(t))$$

> 📝 The assembled cube is not perfectly symmetric, so the sensor's 0° and the actual balance
> point are slightly offset. This formula automatically learns and corrects that offset. A larger $K\_t$ corrects faster.

**Step 2: Compute target angular velocity**

$$\omega_{target} = K_a \cdot (\theta_{target} - \theta)$$

The target angular velocity is derived from the angle error.

**Step 3: Angular velocity PID control**

$$P = \omega_{target} - \omega_{gyro}$$

$$I = \theta \quad \text{（角度そのものを積分項として使用）}$$

$$D = \omega_{gyro}(t) - \omega_{gyro}(t-1) \quad \text{（微分先行型）}$$

$$u = K_p \cdot P + K_i \cdot I - K_d \cdot D$$

> 📝 **What is derivative-on-measurement?**
> The standard D term uses the "rate of change of error," but here we use the "rate of change of gyro angular velocity."
> This technique prevents a sudden spike in output (derivative kick) when the setpoint changes abruptly.

### 6.3 Discretization (Digital Implementation)

The microcontroller implementation uses discrete time:

$$P_k = \omega_{target,k} - \omega_{gyro,k}$$

$$I_k = I_{k-1} + P_k \cdot \Delta t$$

$$D_k = \omega_{gyro,k} - \omega_{gyro,k-1}$$

$$u_k = K_p \cdot P_k + K_i \cdot I_k - K_d \cdot D_k$$

Control period: $\Delta t = 10$ ms (100 Hz) — from the code: `if (currentTime - loopTimer >= 10000)`.

### 6.4 Initial PID Parameter Values

Initial values extracted from the code:

| Parameter | Unit 1 (ESP32) | Unit 2 (Pico) | Role |
|---|:---:|:---:|---|
| $K\_t$ (Ks) | 1.0 | 1.3 | Target angle correction speed |
| $K\_a$ (Kp_angle) | 5.0 | 5.5 | Angle-to-angular-velocity conversion gain |
| $K\_p$ | 60.0 | 32.0 | Proportional gain |
| $K\_i$ | 12.0 | 45.0 | Integral gain |
| $K\_d$ | 90.0 | 95.0 | Derivative gain |

---

## 7. Motor Mixing

### 7.1 Mixing Matrix

The Roll/Pitch PID outputs are distributed to the three motors:

$$\begin{bmatrix} u_{CTR} \\ u_{RH} \\ u_{LH} \end{bmatrix} = \begin{bmatrix} 1 & 0 \\ 0.5 & 0.866 \\ -0.5 & 0.866 \end{bmatrix} \begin{bmatrix} PID_{Roll} \\ PID_{Pitch} \end{bmatrix}$$

Expanding:

$$u_{CTR} = PID_{Roll}$$

$$u_{RH} = 0.5 \cdot PID_{Roll} + 0.866 \cdot PID_{Pitch}$$

$$u_{LH} = -0.5 \cdot PID_{Roll} + 0.866 \cdot PID_{Pitch}$$

### 7.2 Geometric Derivation

Why $0.866$ and $0.5$?

The three motors are arranged at **120° intervals** when viewed from above in the corner-standing position:

```
            0° (CTR)
            │
     240°───●───120°
     (LH)       (RH)
```

Each motor's contribution relative to the Roll axis (0° direction):

$$\text{Roll component} = \cos(\alpha)$$
$$\text{Pitch component} = \sin(\alpha)$$

| Motor | Angle α | cos(α) | sin(α) |
|---|:---:|:---:|:---:|
| CTR | 0° | 1.0 | 0.0 |
| RH | 120° → **Roll: cos60°, Pitch: cos30°** | 0.5 | 0.866 |
| LH | 240° → **Roll: -cos60°, Pitch: cos30°** | -0.5 | 0.866 |

### 7.3 Yaw Axis Control (Unit 2 Only)

Unit 2 adds Yaw (z-axis rotation) control:

$$u_{CTR} = PID_{Roll} + PID_{Yaw}$$

$$u_{RH} = 0.5 \cdot PID_{Roll} + 0.866 \cdot PID_{Pitch} - PID_{Yaw}$$

$$u_{LH} = -0.5 \cdot PID_{Roll} + 0.866 \cdot PID_{Pitch} + PID_{Yaw}$$

Yaw control is achieved by applying torque in the **same direction** to all three wheels.

---

## 8. Attitude Estimation Algorithm

### 8.1 Problem Statement

The MPU6050 has two types of sensors:

| Sensor | Measurement | Strength | Weakness |
|---|---|---|---|
| Accelerometer | Gravity direction → angle | No drift | Sensitive to vibration and acceleration |
| Gyroscope | Angular velocity → angle (via integration) | Fast response | Drifts over time |

> 📝 **Why can't we use just one sensor?**
>
> - **Accelerometer only**: You can determine tilt from the direction of gravity, but motor vibrations make the readings very noisy.
>   Additionally, centrifugal forces from the spinning wheels are indistinguishable from gravity.
>
> - **Gyroscope only**: Integrating angular velocity gives you the angle, but small errors accumulate continuously (drift).
>   After just 30 seconds, the indicated angle can be completely wrong.
>
> → **Combining both compensates for each sensor's weaknesses** — that's the idea behind the complementary filter.

### 8.2 Complementary Filter

This project uses a **complementary filter** to fuse both sensors:

$$\theta_{est} = \alpha \cdot (\theta_{prev} + \omega_{gyro} \cdot \Delta t) + (1 - \alpha) \cdot \theta_{acc}$$

- $\alpha$: Filter coefficient (0.9–0.99, biased toward the gyro)
- $\omega\_{gyro} \cdot \Delta t$: Angular change obtained by integrating the gyro's angular velocity
- $\theta\_{acc}$: Angle computed from the accelerometer

> 📝 **Understanding the complementary filter intuitively:**
>
> ```
> 短期的（高周波）→ ジャイロを信頼（振動に強い、ドリフト前なら正確）
> 長期的（低周波）→ 加速度を信頼（ドリフトしない、真の重力方向がわかる）
> ```
>
> If $\alpha = 0.94$, it means "trust the gyro 94% and correct with the accelerometer 6%."
> Over short timescales, the gyro dominates for fast response; over long timescales, the accelerometer corrects drift.

### 8.3 Implementation Algorithm (Code Analysis)

In the actual code, the complementary filter is implemented as **gravity vector estimation**:

**Step 1: Rotate the gravity vector using the gyro**

$$\vec{V}_g' = \vec{V}_g + \vec{\omega} \times \vec{V}_g \cdot \Delta t$$

Update the direction of the gravity vector using the gyro's angular velocity (first-order approximation of a rotation matrix).

> 📝 The cross product $\vec{\omega} \times \vec{V}\_g$ computes the direction in which the
> gravity vector $V\_g$ rotates due to the angular velocity vector $\omega$.

**Step 2: Correction using the accelerometer (low-pass filter)**

$$\vec{V}_g = \vec{V}_g' + \frac{1}{16}(\vec{a}_{LPF} - \vec{V}_g')$$

Drift is corrected using the accelerometer values. $1/16$ corresponds to the bit shift `>> 4`.

> 📝 $\frac{1}{16}$ corresponds to $(1 - \alpha)$ in the complementary filter.
> That is, $\alpha = 15/16 = 0.9375$ (approximately 94% gyro trust).
> Using bit shifts enables high-speed computation on a microcontroller.

**Step 3: Computing angles**

$$\theta_{Roll} = \text{atan2}(V_{g,y}, V_{g,z})$$

$$\theta_{Pitch} = -\text{atan2}(V_{g,x}, \sqrt{V_{g,y}^2 + V_{g,z}^2})$$

$$\theta_{Yaw} += -\omega_z \cdot \Delta t \quad \text{（ジャイロ積分のみ）}$$

> ⚠️ Since the Yaw angle relies solely on gyro integration, it drifts over extended periods.

---

## 9. Stability Condition Analysis

### 9.1 Controllability

Conditions for maintaining the inverted position:

1. **Sufficient torque**: $\tau\_{max} > mgl\theta\_{max}$
2. **Sufficient response speed**: The control period $\Delta t$ must be much shorter than the system's time constant
3. **Accurate attitude estimation**: IMU accuracy and complementary filter bandwidth

### 9.2 System Time Constant

From the eigenvalues of the linearized model, the toppling time constant is:

$$T = \frac{1}{\sqrt{mgl/I_{body}}}$$

Using this project's values ($m = 0.7$ kg, $l = 0.118$ m, $I\_{body} = ma^2/6$):

$$I_{body} = \frac{0.7 \times 0.136^2}{6} = 0.00216 \text{ kg·m}^2$$

$$T = \frac{1}{\sqrt{\frac{0.7 \times 9.81 \times 0.118}{0.00216}}} = \frac{1}{\sqrt{375}} \approx 0.052 \text{ s} \approx 52 \text{ ms}$$

→ The 10 ms control period (100 Hz) is well within the 52 ms time constant ✅

### 9.3 Why It Can Balance on a Corner — Summary

The reason it can balance on a corner, in one sentence:

> **Because the reaction torque from the angular acceleration of the reaction wheels exceeds the gravitational toppling torque, and sufficiently fast feedback control continuously corrects any deviation.**

Expressed mathematically:

$$\underbrace{I_{wheel}\dot{\omega}_{wheel}}_{\text{Control torque}} > \underbrace{mgl\sin\theta}_{\text{Toppling torque}} \quad \text{and} \quad \underbrace{\Delta t}_{\text{Control period}} \ll \underbrace{T}_{\text{System time constant}}$$

---

## 10. Summary

| Physical Element | Equation | Implementation in This Project |
|---|---|---|
| Conservation of angular momentum | $L\_{body} + L\_{wheel} = \text{const}$ | 3 reaction wheels |
| Equation of motion | $I\ddot{\theta} = mgl\theta - \tau\_{wheel}$ | $\tau\_{wheel}$ controlled via PID |
| PID control | $u = K\_p P + K\_i I - K\_d D$ | Angular velocity PID (imo Lab. method) |
| Motor mixing | cos 30° / cos 60° distribution matrix | 3 motors in 120° arrangement |
| Attitude estimation | Complementary filter (gravity vector method) | MPU6050 (accelerometer + gyro) |
| Stability condition | $\tau\_{max} > mgl\theta$, $\Delta t \ll T$ | 100 Hz control, time constant 52 ms |

---

## References

1. imo Lab. "[How to Control the Attitude of a 3-Axis Attitude Control Module](https://garchiving.com/how-to-3axis-control-self-balancing-cube/)"
2. remrc. "[Self-Balancing-Cube](https://github.com/remrc/Self-Balancing-Cube)" GitHub
3. willem-pennings. "[balancing-cube](https://github.com/willem-pennings/balancing-cube)" GitHub
4. Classical mechanics textbooks — Euler's rotation equations, rigid body dynamics

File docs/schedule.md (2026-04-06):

# 📅 実験スケジュール・工程表

> 3軸姿勢制御モジュール（Self-Balancing Cube）制作の工程管理

---

## 全体フロー

```
Phase A          Phase B          Phase C          Phase D
部品調達    →    PCB作成     →    メカ組立    →    電気接続
(1-2週間)       (1-2週間)       (1-2日)         (1日)

                                      ↓

Phase E          Phase F          Phase G
FW書込み    →    1軸テスト   →    3軸点倒立
(1日)           (数日)          (数日〜)
```

---

## Phase A: 部品調達

### チェックリスト

- [ ] **モーター発注** — Nidec 24H055M020 ×3（+予備1）
  - 購入先: AliExpress or Amazon.co.jp
  - 到着目安: AliExpress 2-3週間 / Amazon 数日
- [ ] **マイコン発注** — Raspberry Pi Pico W ×1
  - 購入先: 秋月電子 or スイッチサイエンス
- [ ] **IMUセンサ発注** — MPU6050モジュール (GY-521) ×1
- [ ] **電源部品** — 7805レギュレータ、コンデンサ(0.1µF, 33µF)、抵抗(1.5kΩ, 470Ω)
- [ ] **バッテリー** — LiPo 3S 11.1V 500-800mAh
- [ ] **バッテリー充電器** — 3S対応バランス充電器
- [ ] **コネクタ類** — ピンヘッダ、ピンソケット、配線材
- [ ] **ネジ類** — M3ボルト各種、M3ナット、皿小ねじ、スペーサー
- [ ] **シャフトハブ** — 6mm径用 金属製 ×3
- [ ] **電源スイッチ**
- [ ] *(オプション)* INA219モジュール
- [ ] *(オプション)* Bluetoothモジュール HC-05/HC-06

### 並行作業（待ち時間を有効活用）
- モーター到着待ちの間に Phase B（PCB発注）を開始
- ファームウェアの理解・カスタマイズを進める

---

## Phase B: PCB作成

### チェックリスト

- [ ] **ガーバーデータ確認** — `hardware/gerber/` のデータをビューアで確認
- [ ] **PCB発注** — JLCPCB or PCBGOGO にアップロード・発注
  - ガーバーデータ: リポジトリの `hardware/gerber/` を使用
  - 到着目安: 1-2週間
- [ ] **PCB到着・外観確認**
- [ ] **はんだ付け**
  - ピンヘッダ/ピンソケット取付け
  - 7805レギュレータ、コンデンサ、抵抗の実装
  - 通電テスト（テスターで5V出力確認）

---

## Phase C: メカ組立

### 前提条件
- 3Dプリントパーツ印刷済み ✅

### チェックリスト

- [ ] **リアクションホイール作成**
  - wheel_x3.stl ×3 にシャフトハブを取付け
  - 外周にボルト＆ナットで重量バランス調整
- [ ] **モーターブラケット作成**
  - BRKT_motor1_x3 + BRKT_motor2_x12 を組立て
  - モーターをブラケットに固定（低頭ねじ推奨）
- [ ] **モーター側フレーム組立て** (3面)
  - FRAME_motor_x3 にモーターブラケットをビス止め
  - CORNER_CUBEx8 をフレーム角に取付け
- [ ] **基板側フレーム組立て** (3面)
  - FRAME_bord_x3 を組立て
  - BRKT_MPU6050_x1 にMPU6050を固定
  - BRKT_PCBbord_x1 に基板を固定
- [ ] **全体組立て**
  - モーター側3面 + 基板側3面 を合体
  - リアクションホイールをモーターに取付け

---

## Phase D: 電気接続

### チェックリスト

- [ ] **モーター配線**
  - 3モーター → 基板の8ピンコネクタに接続
  - 配線色とピンの対応を確認（逆接注意！）
- [ ] **センサー接続** — MPU6050 → I2C (SDA/SCL)
- [ ] **バッテリー接続** — LiPo → 基板電源
- [ ] **通電テスト**
  - 5V出力確認
  - I2Cスキャンでセンサー応答確認（0x68）
  - モーター単体回転テスト

---

## Phase E: ファームウェア書込み

### チェックリスト

- [ ] **Arduino IDE セットアップ** → [docs/04_software_setup.md](04_software_setup.md)
- [ ] **ファームウェアコンパイル** — `firmware/pico_w/3axis_control.ino`
- [ ] **Pico Wに書込み**
- [ ] **シリアルモニタで基本動作確認**
  - IMUの値が正しく読めているか
  - モーターがPWMで回転するか
  - Bluetooth接続できるか

---

## Phase F: 1軸テスト（辺倒立）

### チェックリスト

- [ ] **1軸モード** — コードの `vertical == 1` 状態で1モーターのみ制御
- [ ] **辺（稜線）の上に立てて** Roll軸のみの倒立テスト
- [ ] **PIDゲイン調整** — Processing GUI で Kp/Ki/Kd を調整
- [ ] **安定倒立の達成**（数秒以上）

---

## Phase G: 3軸点倒立 & チューニング

### チェックリスト

- [ ] **3軸モード** — コードの `vertical == 2` 状態で3モーター制御
- [ ] **角（頂点）の上に立てて** 点倒立テスト
- [ ] **PIDゲイン調整** — Roll/Pitch同時に調整
- [ ] **Yaw軸制御追加** — Kz パラメータ調整
- [ ] **安定点倒立の達成** 🎉
- [ ] **重量バランス微調整** — ホイール外周のボルトで調整

---

## 📝 注意事項

- **LiPoバッテリーの取扱い注意** — 過放電・過充電・物理的損傷に注意
- **モーター電源の逆接続厳禁** — Nidec 24H の内蔵ドライバが破損する
- **広い平地で作業** — 制御不安定時にキューブが飛び跳ねる可能性あり
- **最初は手で支えながら** — いきなり離さず、制御の挙動を確認してから

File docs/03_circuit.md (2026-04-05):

# 🔌 回路図・配線ガイド

> Raspberry Pi Pico W ベース（2号機）の回路構成

---

## 回路図

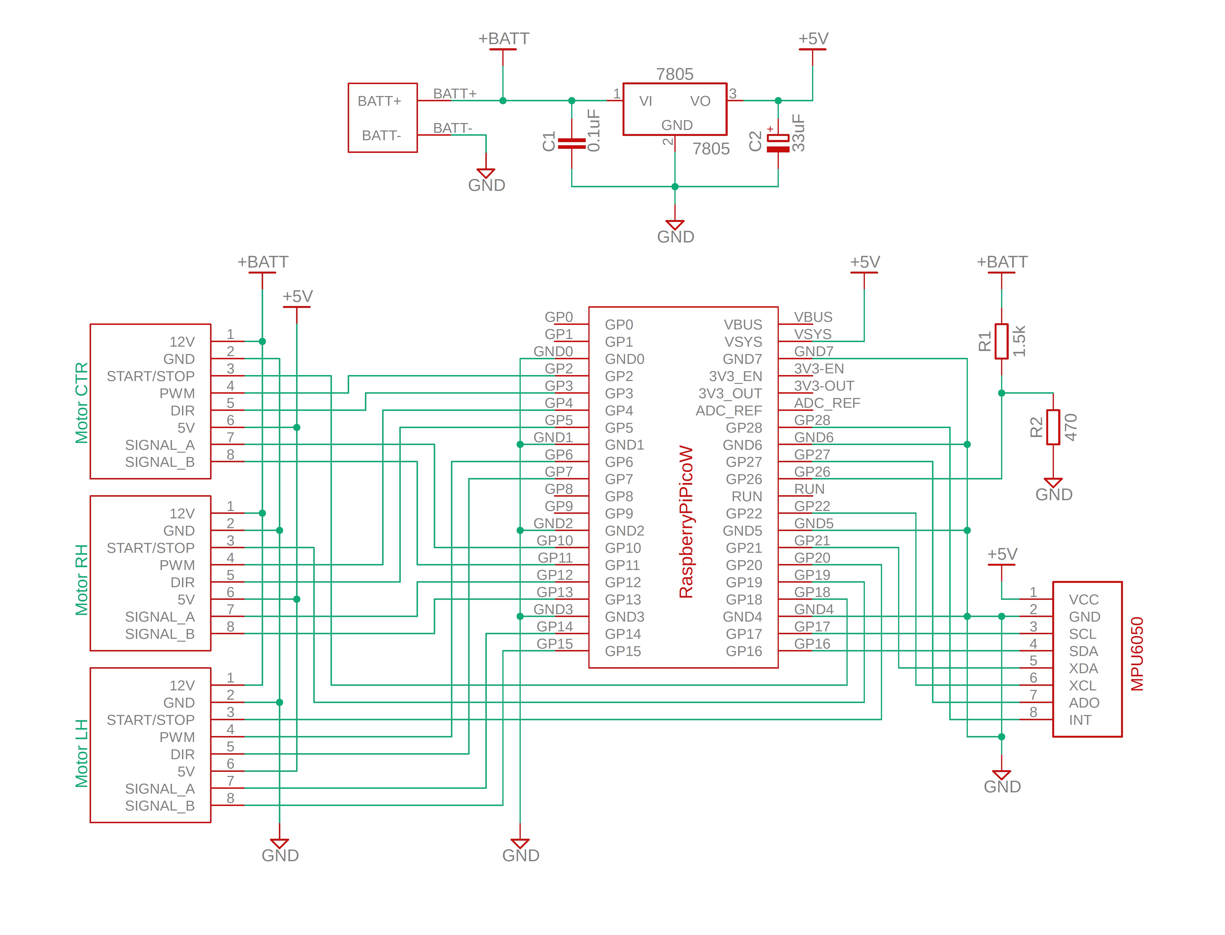
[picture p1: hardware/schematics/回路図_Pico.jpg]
回路図


---

## システム構成図

```
                    ┌─────────────┐
    +BATT (11.1V)──→│   7805      │──→ +5V
                    │  C1=0.1µF   │      │
                    │  C2=33µF    │      ├──→ Pico W (VSYS)
                    └─────────────┘      ├──→ MPU6050 (VCC)
                         │               └──→ Motor 1,2,3 (Pin6: 5V)
                         │
              R1=1.5kΩ ──┤
                         ├──→ GP26 (ADC: バッテリー電圧)
              R2=470Ω  ──┤
                         │
                        GND

    ┌──────────────┐     I2C     ┌──────────┐
    │ Pico W       │────────────→│ MPU6050  │
    │  GP16 (SDA)  │  SDA        │  0x68    │
    │  GP17 (SCL)  │  SCL        └──────────┘
    │              │
    │  GP2  (PWM)  │──→ Motor CTR (Pin4)
    │  GP3  (DIR)  │──→ Motor CTR (Pin5)
    │  GP18 (SS)   │──→ Motor CTR (Pin3)
    │  GP10 (ENCA) │←── Motor CTR (Pin7)
    │  GP11 (ENCB) │←── Motor CTR (Pin8)
    │              │
    │  GP4  (PWM)  │──→ Motor RH  (Pin4)
    │  GP5  (DIR)  │──→ Motor RH  (Pin5)
    │  GP19 (SS)   │──→ Motor RH  (Pin3)
    │  GP12 (ENCA) │←── Motor RH  (Pin7)
    │  GP13 (ENCB) │←── Motor RH  (Pin8)
    │              │
    │  GP6  (PWM)  │──→ Motor LH  (Pin4)
    │  GP7  (DIR)  │──→ Motor LH  (Pin5)
    │  GP20 (SS)   │──→ Motor LH  (Pin3)
    │  GP14 (ENCA) │←── Motor LH  (Pin7)
    │  GP15 (ENCB) │←── Motor LH  (Pin8)
    └──────────────┘
```

---

## Raspberry Pi Pico W ピンアサイン

```
                ┌─────────────┐
       GP0  ────┤ 1        40 ├──── VBUS
       GP1  ────┤ 2        39 ├──── VSYS ← +5V
      GND0  ────┤ 3        38 ├──── GND
  CTR PWM → GP2 ┤ 4        37 ├──── 3V3_EN
  CTR DIR → GP3 ┤ 5        36 ├──── 3V3_OUT
   RH PWM → GP4 ┤ 6        35 ├──── ADC_REF
   RH DIR → GP5 ┤ 7        34 ├──── GP28
      GND1  ────┤ 8        33 ├──── GND
   LH PWM → GP6 ┤ 9        32 ├──── GP27
   LH DIR → GP7 ┤10        31 ├──── GP26 ← BATT ADC
       GP8  ────┤11        30 ├──── RUN
       GP9  ────┤12        29 ├──── GP22
      GND2  ────┤13        28 ├──── GND
 CTR ENC A → GP10┤14       27 ├──── GP21
 CTR ENC B → GP11┤15       26 ├──── GP20 ← LH SS
  RH ENC A → GP12┤16       25 ├──── GP19 ← RH SS
  RH ENC B → GP13┤17       24 ├──── GP18 ← CTR SS
      GND3  ────┤18        23 ├──── GND
 LH ENC A → GP14┤19       22 ├──── GP17 ← I2C SCL
 LH ENC B → GP15┤20       21 ├──── GP16 ← I2C SDA
                └─────────────┘
```

---

## モーター8ピンコネクタ配線表

| ピン | 信号名 | Motor CTR | Motor RH | Motor LH |
|:---:|---|:---:|:---:|:---:|
| 1 | +12V (モーター電源) | +BATT | +BATT | +BATT |
| 2 | GND | GND | GND | GND |
| 3 | START/STOP (SS) | GP18 | GP19 | GP20 |
| 4 | PWM (速度制御) | GP2 | GP4 | GP6 |
| 5 | DIR (方向) | GP3 | GP5 | GP7 |
| 6 | +5V (エンコーダ電源) | +5V | +5V | +5V |
| 7 | SIGNAL_A (エンコーダ) | GP10 | GP12 | GP14 |
| 8 | SIGNAL_B (エンコーダ) | GP11 | GP13 | GP15 |

---

## バッテリー電圧モニタ回路

```
+BATT (11.1V) ─── R1 (1.5kΩ) ──┬── R2 (470Ω) ─── GND
                                 │
                                 └── GP26 (ADC入力)
```

**分圧計算:**

$$V_{ADC} = V_{BATT} \times \frac{R_2}{R_1 + R_2} = V_{BATT} \times \frac{470}{1500 + 470}$$

| バッテリー状態 | V_BATT | V_ADC | ADC値 (12bit) |
|:---:|:---:|:---:|:---:|
| 満充電 | 12.6V | 3.00V | 3723 |
| 定格 | 11.1V | 2.65V | 3281 |
| 要充電 | 9.9V | 2.36V | 2927 |

---

## PCB発注手順（JLCPCB）

1. [JLCPCB](https://jlcpcb.com/) にアカウント作成
2. 「Order Now」→「Add Gerber File」
3. `hardware/gerber/` フォルダ内の全ファイルをZIPにまとめてアップロード
4. 基板設定:
   - Layers: 2
   - PCB Qty: 5（最小ロット）
   - PCB Color: お好みで
   - Surface Finish: HASL(有鉛) が最安
5. 注文・決済（$2〜5 + 送料）
6. 到着まで約1-2週間

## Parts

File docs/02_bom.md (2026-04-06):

# 3軸姿勢制御モジュール（Self-Balancing Cube）部品表（BOM）

> 参考設計: imo Lab. (garchiving.com)
> 作成日: 2026-04-05

---

## 📋 バージョン比較まとめ

| 項目 | 1号機（ESP32版） | 2号機（Pico版） |
|---|:---:|:---:|
| マイコン | ESP32 DevKit V1 | Raspberry Pi Pico W |
| IMU | MPU6050 | MPU6050 |
| 電流/電圧センサ | INA219 ✅ | なし（ADCで電圧のみ） |
| モータードライバ | PWM/DIR/BRAKE型 ×3 | PWM/DIR/SS型 ×3 |
| モーター | ドライバ内蔵BLDC ×3 | ドライバ内蔵BLDC ×3 |
| エンコーダ | あり（未使用） | あり（1軸使用） |
| Bluetooth | ESP32内蔵 SPP | 外部BTモジュール必要 |
| Yaw軸制御 | なし（2軸: Roll/Pitch） | あり（3軸: Roll/Pitch/Yaw） |
| 筐体サイズ | □150mm | □136mm（小型） |
| 基板 | カスタムPCB | カスタムPCB |
| **おすすめ** | **入門向け（シンプル）** | **完成度高い（3軸制御）** |

### 💡 推奨: 2号機（Pico版）をベースに制作
- 3軸（Yaw含む）の完全な姿勢制御
- 小型・軽量
- Raspberry Pi Pico Wは入手性◎・安価
- エンコーダ対応でモーター回転数フィードバック可能

---

## 🔧 完全部品表（2号機ベース）

### 1. マイコン・センサー類

| # | 部品名 | 型番/仕様 | 数量 | 参考価格 | 購入先候補 |
|---|---|---|:---:|---:|---|
| 1 | マイコンボード | **Raspberry Pi Pico W** | 1 | ¥1,240 | [秋月電子](https://akizukidenshi.com/catalog/g/g117947/)（最安）, [Amazon](https://www.amazon.co.jp/dp/B0BB69CH2T) |
| 2 | 6軸IMUセンサ | **MPU6050モジュール** (GY-521) | 1 | ¥220〜 | [Amazon 5個セット](https://www.amazon.co.jp/dp/B07MPBMRWD), [Yahoo!](https://store.shopping.yahoo.co.jp/officek-diga/3axes-gyrosensor.html) |
| 3 | 電流/電圧センサ | **INA219モジュール** (オプション) | 1 | ¥400 | Amazon で「INA219」検索 |

> ⚠️ INA219は2号機のコードでは未使用だが、バッテリー監視に有用。1号機コードにはある。

### 2. モーター（ドライバ＆エンコーダ内蔵型）

> 🔑 **回路図から判明した重要事実**:
> モーターは**ドライバ回路＋エンコーダが内蔵された一体型モジュール**です。
> 別途モータードライバICを購入する必要はありません！

各モーターモジュールは **8ピンコネクタ** で以下の信号を持つ:

| ピン | 信号名 | 説明 |
|:---:|---|---|
| 1 | 12V | モーター電源（バッテリー直結） |
| 2 | GND | グランド |
| 3 | START/STOP | 運転/停止制御（コード上: SS） |
| 4 | PWM | 速度制御（8bit, ~8kHz） |
| 5 | DIR | 回転方向 |
| 6 | 5V | エンコーダ用ロジック電源 |
| 7 | SIGNAL_A | エンコーダA相 |
| 8 | SIGNAL_B | エンコーダB相 |

| # | 部品名 | 型番/仕様 | 数量 | 参考価格 | 購入先候補 |
|---|---|---|:---:|---:|---|
| 4 | モーターモジュール | **ドライバ内蔵DCモーター（エンコーダ付き・8ピン）** | 3 | ¥800-2,000/個 | AliExpress, Amazon, Taobao |
| 5 | シャフトハブ | **金属製シャフトハブ 6mm径用**（イモネジ固定式） | 3 | ¥200-500/個 | Amazon, モノタロウ |

> 💡 **シャフトハブ**: モーターシャフト(6mm)にリアクションホイールを固定する部品。
> 3Dプリントのホイール(wheel_x3.stl)にネジ止めする。金属製推奨（強度・精度）。

#### モーター選定の詳細
**要件（回路図・コードから確定）:**
- **8ピンインターフェース**: 12V / GND / START-STOP / PWM / DIR / 5V / ENC-A / ENC-B
- **動作電圧**: 12V（3S LiPo = 11.1V〜12.6V）
- **PWM制御**: 8bit分解能（0-255）、約8kHz
- **ドライバ内蔵**: H-bridge駆動回路が内蔵されている
- **エンコーダ内蔵**: 2相（A/B）クワドラチャエンコーダ

**候補モーター:**

#### ✅ 最有力候補: **Nidec 24H055M020**（ドライバ内蔵BLDCサーボモーター）

imo Lab.のブログで「Nidec」ロゴのモーターをテストした記述があり、
回路図の8ピンインターフェースとコードの制御方式（反転PWM: `255 - abs(val)`）が
Nidec 24Hシリーズの仕様と完全に一致。

| 仕様項目 | 値 |
|---|-----|
| 型番 | **Nidec 24H055M020** (またはNidec 24Hシリーズ) |
| 種類 | ブラシレスDCサーボモーター（ドライバ内蔵） |
| 動作電圧 | DC 12V（10-13V） |
| 最高回転数 | 約 3,900 RPM |
| サイズ | Φ42mm × 34mm |
| シャフト径 | **6mm** → シャフトハブは6mm用を選定 |
| 重量 | 約 118g |
| エンコーダ | 100ライン（クワドラチャ） |
| 制御 | PWM（デューティ比で速度制御、反転動作） |
| 電子ブレーキ | あり |
| 正逆転 | DIR信号で切替 |

**購入リンク:**

| 購入先 | 価格帯 | URL | 備考 |
|---|---|-----|---|
| **AliExpress** | $5-10 (¥750-1,500) | [Nidec 24H 12V](https://www.aliexpress.com/item/1005006036612599.html) | 中古/分解品が多い、最安 |
| **AliExpress** | $5-10 | [Nidec 24H 9-24V](https://www.aliexpress.com/item/1005005779568014.html) | 電圧範囲広い版 |
| **Amazon.co.jp** | ¥1,500-3,000 | [Nidec 24H 12V](https://www.amazon.co.jp/dp/B0CG57F9DD) | 日本発送あり、やや高い |
| **Amazon.com** | $8-15 | [Nidec 24H](https://www.amazon.com/dp/B0DM1WVXW3) | US版 |

> ⚠️ **注意事項:**
> - 中古品/分解品が多い。シャフトがはすば歯車のものは避ける（平シャフト推奨）
> - 配線色が商品ページと異なることがある（imo Lab.ブログでも指摘）
> - **電源の逆接続厳禁！** 内蔵ドライバが破損する
> - 3個購入する（3軸分）。予備含め4個推奨

**代替モーター（Nidec 24Hが入手困難な場合）:**
1. 汎用DCギヤモーター + 外付けモータードライバ（DRV8876等）で代用可能
   → ただしコード改変（PWM反転ロジック等）が必要
2. 同等の8ピンIF付きドライバ内蔵モーター（AliExpressで類似品を探す）

> ⚠️ **重要**: 3Dモデルのモーターマウント穴径・シャフト径を実測して確認してください。
> STL/STEPファイルは imo Lab. の頒布データに含まれます（本リポジトリには未収録）。
> [BOOTH](https://booth.pm/ja/items/5992975) で ¥800 で入手可能。

### 3. 電源系

> 🔑 **回路図から判明**: 7805レギュレータでバッテリー(11.1V)→5Vに降圧。
> 分圧抵抗(R1=1.5kΩ, R2=470Ω)でバッテリー電圧をADCで監視。

| # | 部品名 | 型番/仕様 | 数量 | 参考価格 | 購入先候補 |
|---|---|---|:---:|---:|---|
| 6 | バッテリー | **LiPo 3S (11.1V) 500-800mAh** 小型 | 1 | ¥2,000-3,500 | [Amazon「3S 11.1V 500mAh」](https://www.amazon.co.jp/s?k=3S+11.1V+500mAh+Lipo) |
| 7 | LiPo充電器 | **バランス充電器** (3S対応) | 1 | ¥3,000-5,000 | [Amazon「Lipo 充電器 3S」](https://www.amazon.co.jp/s?k=Lipo+%E5%85%85%E9%9B%BB%E5%99%A8+3S) |
| 8 | 5Vレギュレータ | **NJM7805FA** (TO-220) | 1 | ¥60 | [秋月電子](https://akizukidenshi.com/catalog/g/g108678/) |
| 9 | 入力コンデンサ | **0.1µF セラミック** (C1) | 1 | ¥10 | 秋月電子 |
| 10 | 出力コンデンサ | **33µF 電解** (C2) | 1 | ¥20 | 秋月電子 |
| 11 | 分圧抵抗 R1 | **1.5kΩ** (バッテリー電圧監視) | 1 | ¥10 | 秋月電子 |
| 12 | 分圧抵抗 R2 | **470Ω** (バッテリー電圧監視) | 1 | ¥10 | 秋月電子 |
| 13 | 電源スイッチ | **スライドスイッチ** or トグルスイッチ | 1 | ¥100 | 秋月電子 |
| 14 | コネクタ | **XT30 / JST-XH** バッテリーコネクタ | 1セット | ¥200 | Amazon |

> 💡 **バッテリー電圧モニタ**:
> 分圧比 = 470 / (1500 + 470) = 0.238
> 満充電12.6V → ADC入力 3.0V（Pico ADC 3.3V範囲内 ✅）

### 4. 基板・コネクタ類

| # | 部品名 | 型番/仕様 | 数量 | 参考価格 | 購入先候補 |
|---|---|---|:---:|---:|---|
| 11 | カスタム基板 | **PCB発注** (ガーバーデータ使用) | 5枚〜 | $2-5 | [JLCPCB](https://jlcpcb.com/), [PCBGOGO](https://www.pcbgogo.jp/) |
| 12 | ピンヘッダ | **2.54mmピンヘッダ** (オス) | 2-3列 | ¥100 | 秋月電子 |
| 13 | ピンソケット | **2.54mmピンソケット** (メス) | 2-3列 | ¥100 | 秋月電子 |
| 14 | 配線材 | **AWG24-26 シリコンワイヤー** 各色 | 適量 | ¥500 | Amazon |
| 15 | コネクタ | **JST-PH / JST-XH** モーター配線用 | 適量 | ¥300 | 秋月電子 |

### 5. 機械部品（ネジ・スペーサー）

| # | 部品名 | 仕様 | 数量 | 参考価格 | 備考 |
|---|---|---|:---:|---:|---|
| 16 | M3ボルト | 各種長さセット（低頭ねじ推奨） | 1セット | ¥500-800 | モーターマウント、フレーム組立 |
| 17 | M3ナット | 標準ナット | 適量 | ¥200 | フレーム固定 |
| 18 | M3スペーサー | 基板固定用（メス-メス or オス-メス） | 4-8個 | ¥300 | 基板ブラケット |
| 19 | M2ボルト | センサーマウント用 | 適量 | ¥200 | MPU6050固定 |
| 20 | 皿小ねじ M3 | リアクションホイール外周用 | 30-40個 | ¥300 | 重量バランス調整 |
| 21 | タイラップ | バッテリー固定用 | 数本 | ¥100 | - |

### 6. Bluetooth通信（2号機の場合）

| # | 部品名 | 型番/仕様 | 数量 | 参考価格 | 備考 |
|---|---|---|:---:|---:|---|
| 22 | Bluetoothモジュール | **HC-05** or **HC-06** SPPモジュール | 1 | ¥500-800 | Pico W内蔵BTは対応要確認 |

> ⚠️ Pico Wは内蔵BT対応だが、コード上は `SerialBT.h`（カスタムライブラリ）を使用。
> Pico W内蔵BTで直接使えるか、外部HC-05等が必要かは回路図で確認。

---

## 📌 完全ピン配線表（2号機 Pico版・回路図より確定）

### Raspberry Pi Pico W ピンアサイン

```
                ┌─────────────┐
       GP0  ────┤ 1        40 ├──── VBUS
       GP1  ────┤ 2        39 ├──── VSYS ← +5V
      GND0  ────┤ 3        38 ├──── GND
  CTR PWM → GP2 ┤ 4        37 ├──── 3V3_EN
  CTR DIR → GP3 ┤ 5        36 ├──── 3V3_OUT
   RH PWM → GP4 ┤ 6        35 ├──── ADC_REF
   RH DIR → GP5 ┤ 7        34 ├──── GP28
      GND1  ────┤ 8        33 ├──── GND
   LH PWM → GP6 ┤ 9        32 ├──── GP27
   LH DIR → GP7 ┤10        31 ├──── GP26 ← BATT ADC
       GP8  ────┤11        30 ├──── RUN
       GP9  ────┤12        29 ├──── GP22
      GND2  ────┤13        28 ├──── GND
 CTR ENC A → GP10┤14       27 ├──── GP21
 CTR ENC B → GP11┤15       26 ├──── GP20 ← LH SS
  RH ENC A → GP12┤16       25 ├──── GP19 ← RH SS
  RH ENC B → GP13┤17       24 ├──── GP18 ← CTR SS
      GND3  ────┤18        23 ├──── GND
 LH ENC A → GP14┤19       22 ├──── GP17 ← I2C SCL
 LH ENC B → GP15┤20       21 ├──── GP16 ← I2C SDA
                └─────────────┘
```

### モーターコネクタ配線（8ピン × 3モーター）

| ピン | Motor CTR | Motor RH | Motor LH |
|:---:|---|---|---|
| 1 (12V) | +BATT | +BATT | +BATT |
| 2 (GND) | GND | GND | GND |
| 3 (SS) | GP18 | GP19 | GP20 |
| 4 (PWM) | GP2 | GP4 | GP6 |
| 5 (DIR) | GP3 | GP5 | GP7 |
| 6 (5V) | +5V | +5V | +5V |
| 7 (ENC-A) | GP10 | GP12 | GP14 |
| 8 (ENC-B) | GP11 | GP13 | GP15 |

### MPU6050 接続

| MPU6050ピン | 接続先 |
|---|---|
| VCC | +5V |
| GND | GND |
| SCL | GP17 |
| SDA | GP16 |
| XDA | 未接続 |
| XCL | 未接続 |
| ADO | 未接続 |
| INT | 未接続 |

### バッテリー電圧モニタ

```
+BATT ──┬── R1 (1.5kΩ) ──┬── R2 (470Ω) ──── GND
         │                 │
         │                 └── GP26 (ADC入力)
         │
         └── 7805 VI ── 7805 VO ── +5V
             C1=0.1µF      C2=33µF
```

### 7. 3Dプリントパーツ（印刷済み ✅）

#### 2号機パーツ一覧
| ファイル名 | 数量 | 用途 |
|---|:---:|---|
| BRKT_motor1_x3.stl | 3 | モーターブラケット（ベース） |
| BRKT_motor2_x12.stl | 12 | モーターブラケット（脚） |
| BRKT_MPU6050_x1.stl | 1 | IMUセンサーブラケット |
| BRKT_PCBbord_x1.stl | 1 | 基板ブラケット |
| CORNER_CUBEx8.stl | 8 | キューブ型コーナースペーサー |
| FRAME_bord_x3.stl | 3 | フレーム（基板/センサー側） |
| FRAME_motor_x3.stl | 3 | フレーム（モーター側） |
| wheel_x3.stl | 3 | リアクションホイール |

> ⚠️ STLファイルは imo Lab. の頒布データに含まれます（本リポジトリには未収録）。
> [BOOTH](https://booth.pm/ja/items/5992975) で入手可能。

---

## 💰 概算費用

| カテゴリ | 概算 |
|---|-----:|
| マイコン（Pico W）+ センサー | ¥1,900 |
| モーターモジュール（ドライバ内蔵）×3 | ¥2,400-6,000 |
| バッテリー・充電器 | ¥5,000-8,500 |
| 電源回路部品（7805, コンデンサ, 抵抗） | ¥100 |
| 基板（PCB発注） | ¥500-1,000 |
| コネクタ・配線材 | ¥1,000 |
| ネジ・スペーサー | ¥1,500 |
| Bluetoothモジュール | ¥0-800 |
| **合計（概算）** | **¥12,400 - ¥19,800** |

> ※ 3Dプリントパーツ（印刷済み✅）・工具・はんだごて等は含まず
> ※ 最大のコスト要因はモーターとバッテリー

---

## 🔍 要確認事項（Next Steps）

### 最優先で確認すべきこと
1. **✅ 回路図解読完了** — モーターは「ドライバ＆エンコーダ内蔵8ピンモジュール」と判明
2. **モーターの入手** — 同型の8ピンモーターモジュールを探す
   - AliExpress/Taobaoで「DC motor built-in driver encoder 8pin 12V」で検索
   - imo Lab.ブログで紹介されたNidec製モーターに類似のもの
   - または [BOOTH](https://booth.pm/ja/items/5992975) で¥800のレシピを購入して正確な型番を確認
3. **3Dモデルからモーターサイズを確認** — ブラケットのモーター取付穴の径とピッチ
   - 3Dモデルファイル `Assy.step` をCADで開いて確認（imo Lab. 頒布データに含まれる。本リポジトリには未収録）
4. **バッテリーサイズ** — 基板ブラケットに収まるサイズを確認

### imo Lab.のレシピ購入を検討
- [BOOTH](https://booth.pm/ja/items/5992975) で ¥800 で完全な設計データセット入手可能
- 正確なBOM、組立手順が含まれる可能性あり

### Nidec 24Hモーター 参考リソース
- [Arduino Forum: Nidec 24H055M020 解析](https://forum.arduino.cc/t/nidec-24h055m020-operation-solved-mostly/1429057) — ピンアウト逆解析
- [GitHub: Nidec 24H制御ライブラリ](https://github.com/gcharles81/Nidec_24H_motor_control) — Arduinoコード例
- [YouTube: Nidec 24H配線方法](https://www.youtube.com/watch?v=ZOyGFHkPrV4) — 配線解説動画
- [Arduino Forum: Self Balancing + Nidec 24H](https://forum.arduino.cc/t/self-balancing-reaction-wheel-problems-with-nidec-24h-055m020/1139918) — 実用例

---

## 🛒 お買い物チェックリスト（購入先リンク付き）

> コピペして使える購入チェックリスト。上から優先度順。

### 最優先（リードタイム長い）

- [ ] **モーター Nidec 24H055M020 ×4**（3個使用 + 予備1）
  - 🏪 [Amazon.co.jp RUOHARD](https://www.amazon.co.jp/dp/B0FV3JQVN5) — ¥1,500〜/個、数日で届く
  - 🏪 [Amazon.co.jp MESKE](https://www.amazon.co.jp/dp/B0D28GHSK1) — ¥1,500〜/個
  - 🏪 [AliExpress（最安）](https://ja.aliexpress.com/item/1005005567692278.html) — ¥750〜/個、到着2-3週間
  - ⚠️ **Dカット軸を選ぶ。はすば歯車シャフトは避ける**

- [ ] **PCB基板発注**（ガーバーデータ: `hardware/gerber/` をZIP化してアップロード）
  - 🏪 [JLCPCB](https://jlcpcb.com/) — $2〜5 + 送料、到着1-2週間
  - 🏪 [PCBGOGO](https://www.pcbgogo.jp/) — 日本語対応

- [ ] **LiPo 3S バッテリー 11.1V 500-800mAh ×1**
  - 🏪 [Amazon「3S 11.1V 500mAh Lipo」で検索](https://www.amazon.co.jp/s?k=3S+11.1V+500mAh+Lipo)
  - ⚠️ サイズを基板ブラケットに合わせて選定

- [ ] **LiPo バランス充電器（3S対応）×1**
  - 🏪 [Amazon「Lipo 充電器 3S」で検索](https://www.amazon.co.jp/s?k=Lipo+%E5%85%85%E9%9B%BB%E5%99%A8+3S)

### 秋月電子でまとめ買い

- [ ] **Raspberry Pi Pico W ×1** — [秋月 ¥1,240](https://akizukidenshi.com/catalog/g/g117947/)
- [ ] **三端子レギュレータ NJM7805FA ×1** — [秋月 ¥60](https://akizukidenshi.com/catalog/g/g108678/)
- [ ] **積層セラミックコンデンサ 0.1µF ×1** — 秋月 ¥10
- [ ] **電解コンデンサ 33µF 25V ×1** — 秋月 ¥20
- [ ] **カーボン抵抗 1.5kΩ ×1** — 秋月 ¥10
- [ ] **カーボン抵抗 470Ω ×1** — 秋月 ¥10
- [ ] **ピンヘッダ 1×40 ×2** — 秋月 ¥50/本
- [ ] **ピンソケット 1×40 ×2** — 秋月 ¥80/本
- [ ] **スライドスイッチ ×1** — 秋月 ¥50〜

### Amazon でまとめ買い

- [ ] **MPU6050 (GY-521) モジュール** — [Amazon 5個セット ¥1,100](https://www.amazon.co.jp/dp/B07MPBMRWD)
- [ ] **シャフトハブ/カップリング 6mm ×3** — [Amazon「シャフトカップリング 6mm」](https://www.amazon.co.jp/s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)
- [ ] **M3ボルト・ナットセット** — Amazon「M3 ボルト ナット セット」¥500〜
- [ ] **M2ボルト・ナットセット** — Amazon「M2 ボルト ナット セット」¥300〜
- [ ] **M3 皿小ねじ ×40本** — Amazon ¥300〜（ホイールバランス用）
- [ ] **AWG24 シリコンワイヤー** — Amazon ¥500〜
- [ ] **タイラップ** — Amazon or 100均

### オプション

- [ ] **imo Lab. レシピ** — [BOOTH ¥800](https://booth.pm/ja/items/5992975)（正確な型番・組立手順入手）

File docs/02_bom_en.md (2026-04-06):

# Bill of Materials (BOM) — Self-Balancing Cube

> Reference design: imo Lab. (garchiving.com)
> Created: 2026-04-05

> 🌐 **Note for international buyers:**
> AliExpress links ship worldwide. Amazon.co.jp may offer international shipping depending on the seller.
> Akizuki Denshi (秋月電子) is a Japan-only retailer — international buyers should source equivalent parts from local suppliers or AliExpress.

---

## 📋 Version Comparison Summary

| Item | Unit 1 (ESP32 version) | Unit 2 (Pico version) |
|---|:---:|:---:|
| Microcontroller | ESP32 DevKit V1 | Raspberry Pi Pico W |
| IMU | MPU6050 | MPU6050 |
| Current/Voltage sensor | INA219 ✅ | None (voltage only via ADC) |
| Motor driver | PWM/DIR/BRAKE type ×3 | PWM/DIR/SS type ×3 |
| Motors | Driver-integrated BLDC ×3 | Driver-integrated BLDC ×3 |
| Encoder | Available (unused) | Available (1 axis used) |
| Bluetooth | ESP32 built-in SPP | External BT module required |
| Yaw axis control | None (2-axis: Roll/Pitch) | Yes (3-axis: Roll/Pitch/Yaw) |
| Enclosure size | □150mm | □136mm (compact) |
| PCB | Custom PCB | Custom PCB |
| **Recommended** | **Beginner-friendly (simple)** | **More complete (3-axis control)** |

### 💡 Recommendation: Build based on Unit 2 (Pico version)
- Full 3-axis attitude control (including Yaw)
- Compact & lightweight
- Raspberry Pi Pico W is widely available & affordable
- Encoder support enables motor RPM feedback

---

## 🔧 Complete Parts List (Based on Unit 2)

### 1. Microcontroller & Sensors

| # | Part Name | Model / Spec | Qty | Ref. Price | Where to Buy |
|---|---|---|:---:|---:|---|
| 1 | Microcontroller board | **Raspberry Pi Pico W** | 1 | ¥1,240 | [Akizuki Denshi](https://akizukidenshi.com/catalog/g/g117947/) (cheapest, Japan only), [Amazon](https://www.amazon.co.jp/dp/B0BB69CH2T) |
| 2 | 6-axis IMU sensor | **MPU6050 module** (GY-521) | 1 | ¥220~ | [Amazon 5-pack](https://www.amazon.co.jp/dp/B07MPBMRWD), [Yahoo!](https://store.shopping.yahoo.co.jp/officek-diga/3axes-gyrosensor.html) |
| 3 | Current/Voltage sensor | **INA219 module** (optional) | 1 | ¥400 | Search "INA219" on Amazon |

> ⚠️ INA219 is not used in the Unit 2 code, but is useful for battery monitoring. Unit 1 code does use it.

### 2. Motors (with Built-in Driver & Encoder)

> 🔑 **Key finding from the schematic**:
> The motors are **integrated modules with a built-in driver circuit and encoder**.
> There is no need to purchase separate motor driver ICs!

Each motor module has an **8-pin connector** with the following signals:

| Pin | Signal Name | Description |
|:---:|---|---|
| 1 | 12V | Motor power (connected directly to battery) |
| 2 | GND | Ground |
| 3 | START/STOP | Run/stop control (labeled SS in code) |
| 4 | PWM | Speed control (8-bit, ~8 kHz) |
| 5 | DIR | Rotation direction |
| 6 | 5V | Logic power for encoder |
| 7 | SIGNAL_A | Encoder phase A |
| 8 | SIGNAL_B | Encoder phase B |

| # | Part Name | Model / Spec | Qty | Ref. Price | Where to Buy |
|---|---|---|:---:|---:|---|
| 4 | Motor module | **DC motor with built-in driver (encoder, 8-pin)** | 3 | ¥800–2,000/ea | AliExpress, Amazon, Taobao |
| 5 | Shaft hub | **Metal shaft hub for 6 mm shaft** (set-screw type) | 3 | ¥200–500/ea | Amazon, Monotaro |

> 💡 **Shaft hub**: Couples the motor shaft (6 mm) to the reaction wheel.
> Screws into the 3D-printed wheel (wheel_x3.stl). Metal hubs recommended for strength & precision.

#### Motor Selection Details
**Requirements (confirmed from schematic & code):**
- **8-pin interface**: 12V / GND / START-STOP / PWM / DIR / 5V / ENC-A / ENC-B
- **Operating voltage**: 12V (3S LiPo = 11.1–12.6V)
- **PWM control**: 8-bit resolution (0–255), ~8 kHz
- **Built-in driver**: Integrated H-bridge drive circuit
- **Built-in encoder**: 2-phase (A/B) quadrature encoder

**Candidate Motors:**

#### ✅ Top Candidate: **Nidec 24H055M020** (BLDC servo motor with built-in driver)

imo Lab.'s blog mentions testing a motor with a "Nidec" logo,
and the schematic's 8-pin interface plus the code's control method (inverted PWM: `255 - abs(val)`)
are a perfect match for the Nidec 24H series specifications.

| Specification | Value |
|---|---|
| Model | **Nidec 24H055M020** (or Nidec 24H series) |
| Type | Brushless DC servo motor (built-in driver) |
| Operating voltage | DC 12V (10–13V) |
| Max RPM | ~3,900 RPM |
| Dimensions | Φ42 mm × 34 mm |
| Shaft diameter | **6 mm** → select 6 mm shaft hub |
| Weight | ~118 g |
| Encoder | 100 lines (quadrature) |
| Control | PWM (duty cycle for speed, inverted operation) |
| Electronic brake | Yes |
| Forward/Reverse | DIR signal toggle |

**Purchase Links:**

| Retailer | Price Range | URL | Notes |
|---|---|-----|---|
| **AliExpress** | $5–10 (¥750–1,500) | [Nidec 24H 12V](https://www.aliexpress.com/item/1005006036612599.html) | Often used/salvaged parts, cheapest |
| **AliExpress** | $5–10 | [Nidec 24H 9–24V](https://www.aliexpress.com/item/1005005779568014.html) | Wider voltage range version |
| **Amazon.co.jp** | ¥1,500–3,000 | [Nidec 24H 12V](https://www.amazon.co.jp/dp/B0CG57F9DD) | Ships from Japan, slightly pricier |
| **Amazon.com** | $8–15 | [Nidec 24H](https://www.amazon.com/dp/B0DM1WVXW3) | US version |

> ⚠️ **Important Notes:**
> - Many listings are used/salvaged parts. Avoid shafts with helical gears — choose a flat (D-cut) shaft.
> - Wire colors may differ from the product listing (also noted on imo Lab.'s blog).
> - **Never reverse the power supply polarity!** It will damage the built-in driver.
> - Buy 3 (one per axis). Recommend buying 4 including a spare.

**Alternative Motors (if Nidec 24H is unavailable):**
1. Generic DC gearmotor + external motor driver (e.g. DRV8876) can be substituted
   → Code modifications (inverted PWM logic, etc.) will be needed.
2. Similar 8-pin interface motor with built-in driver (search AliExpress for equivalents).

> ⚠️ **Important**: Verify the motor mount hole diameter and shaft diameter against the 3D model.
> STL file: `2号機_Pico版/3Dモデル/BRKT_motor1_x3.stl`
> STEP file: `2号機_Pico版/3Dモデル/Assy.step` — open in CAD to check dimensions.

### 3. Power Supply

> 🔑 **From the schematic**: A 7805 regulator steps down the battery voltage (11.1V) to 5V.
> A voltage divider (R1 = 1.5 kΩ, R2 = 470 Ω) monitors battery voltage via ADC.

| # | Part Name | Model / Spec | Qty | Ref. Price | Where to Buy |
|---|---|---|:---:|---:|---|
| 6 | Battery | **LiPo 3S (11.1V) 500–800 mAh** compact | 1 | ¥2,000–3,500 | [Amazon "3S 11.1V 500mAh"](https://www.amazon.co.jp/s?k=3S+11.1V+500mAh+Lipo) |
| 7 | LiPo charger | **Balance charger** (3S compatible) | 1 | ¥3,000–5,000 | [Amazon "Lipo charger 3S"](https://www.amazon.co.jp/s?k=Lipo+%E5%85%85%E9%9B%BB%E5%99%A8+3S) |
| 8 | 5V regulator | **NJM7805FA** (TO-220) | 1 | ¥60 | [Akizuki Denshi](https://akizukidenshi.com/catalog/g/g108678/) |
| 9 | Input capacitor | **0.1 µF ceramic** (C1) | 1 | ¥10 | Akizuki Denshi |
| 10 | Output capacitor | **33 µF electrolytic** (C2) | 1 | ¥20 | Akizuki Denshi |
| 11 | Voltage divider R1 | **1.5 kΩ** (battery voltage monitor) | 1 | ¥10 | Akizuki Denshi |
| 12 | Voltage divider R2 | **470 Ω** (battery voltage monitor) | 1 | ¥10 | Akizuki Denshi |
| 13 | Power switch | **Slide switch** or toggle switch | 1 | ¥100 | Akizuki Denshi |
| 14 | Connector | **XT30 / JST-XH** battery connector | 1 set | ¥200 | Amazon |

> 💡 **Battery Voltage Monitor**:
> Divider ratio = 470 / (1500 + 470) = 0.238
> Full charge 12.6V → ADC input 3.0V (within Pico ADC 3.3V range ✅)

### 4. PCB & Connectors

| # | Part Name | Model / Spec | Qty | Ref. Price | Where to Buy |
|---|---|---|:---:|---:|---|
| 11 | Custom PCB | **PCB order** (using Gerber data) | 5+ pcs | $2–5 | [JLCPCB](https://jlcpcb.com/), [PCBGOGO](https://www.pcbgogo.jp/) |
| 12 | Pin headers | **2.54 mm pin header** (male) | 2–3 strips | ¥100 | Akizuki Denshi |
| 13 | Pin sockets | **2.54 mm pin socket** (female) | 2–3 strips | ¥100 | Akizuki Denshi |
| 14 | Hook-up wire | **AWG24–26 silicone wire** assorted colors | as needed | ¥500 | Amazon |
| 15 | Connectors | **JST-PH / JST-XH** for motor wiring | as needed | ¥300 | Akizuki Denshi |

### 5. Mechanical Parts (Screws & Spacers)

| # | Part Name | Spec | Qty | Ref. Price | Notes |
|---|---|---|:---:|---:|---|
| 16 | M3 bolts | Assorted lengths (low-profile head recommended) | 1 set | ¥500–800 | Motor mount, frame assembly |
| 17 | M3 nuts | Standard nuts | as needed | ¥200 | Frame fastening |
| 18 | M3 spacers | For PCB mounting (F-F or M-F) | 4–8 pcs | ¥300 | PCB bracket |
| 19 | M2 bolts | For sensor mounting | as needed | ¥200 | MPU6050 mounting |
| 20 | M3 flat-head screws | For reaction wheel perimeter | 30–40 pcs | ¥300 | Weight balance adjustment |
| 21 | Cable ties | For battery mounting | several | ¥100 | — |

### 6. Bluetooth Communication (for Unit 2)

| # | Part Name | Model / Spec | Qty | Ref. Price | Notes |
|---|---|---|:---:|---:|---|
| 22 | Bluetooth module | **HC-05** or **HC-06** SPP module | 1 | ¥500–800 | Check if Pico W's built-in BT is compatible |

> ⚠️ Pico W has built-in Bluetooth, but the code uses `SerialBT.h` (a custom library).
> Whether the Pico W's built-in BT works directly or an external HC-05 is needed — verify against the schematic.

---

## 📌 Complete Wiring Table (Unit 2 Pico Version — Confirmed from Schematic)

### Raspberry Pi Pico W Pin Assignment

```
                ┌─────────────┐
       GP0  ────┤ 1        40 ├──── VBUS
       GP1  ────┤ 2        39 ├──── VSYS ← +5V
      GND0  ────┤ 3        38 ├──── GND
  CTR PWM → GP2 ┤ 4        37 ├──── 3V3_EN
  CTR DIR → GP3 ┤ 5        36 ├──── 3V3_OUT
   RH PWM → GP4 ┤ 6        35 ├──── ADC_REF
   RH DIR → GP5 ┤ 7        34 ├──── GP28
      GND1  ────┤ 8        33 ├──── GND
   LH PWM → GP6 ┤ 9        32 ├──── GP27
   LH DIR → GP7 ┤10        31 ├──── GP26 ← BATT ADC
       GP8  ────┤11        30 ├──── RUN
       GP9  ────┤12        29 ├──── GP22
      GND2  ────┤13        28 ├──── GND
 CTR ENC A → GP10┤14       27 ├──── GP21
 CTR ENC B → GP11┤15       26 ├──── GP20 ← LH SS
  RH ENC A → GP12┤16       25 ├──── GP19 ← RH SS
  RH ENC B → GP13┤17       24 ├──── GP18 ← CTR SS
      GND3  ────┤18        23 ├──── GND
 LH ENC A → GP14┤19       22 ├──── GP17 ← I2C SCL
 LH ENC B → GP15┤20       21 ├──── GP16 ← I2C SDA
                └─────────────┘
```

### Motor Connector Wiring (8-pin × 3 motors)

| Pin | Motor CTR | Motor RH | Motor LH |
|:---:|---|---|---|
| 1 (12V) | +BATT | +BATT | +BATT |
| 2 (GND) | GND | GND | GND |
| 3 (SS) | GP18 | GP19 | GP20 |
| 4 (PWM) | GP2 | GP4 | GP6 |
| 5 (DIR) | GP3 | GP5 | GP7 |
| 6 (5V) | +5V | +5V | +5V |
| 7 (ENC-A) | GP10 | GP12 | GP14 |
| 8 (ENC-B) | GP11 | GP13 | GP15 |

### MPU6050 Connection

| MPU6050 Pin | Connected To |
|---|---|
| VCC | +5V |
| GND | GND |
| SCL | GP17 |
| SDA | GP16 |
| XDA | Not connected |
| XCL | Not connected |
| ADO | Not connected |
| INT | Not connected |

### Battery Voltage Monitor

```
+BATT ──┬── R1 (1.5kΩ) ──┬── R2 (470Ω) ──── GND
         │                 │
         │                 └── GP26 (ADC input)
         │
         └── 7805 VI ── 7805 VO ── +5V
             C1=0.1µF      C2=33µF
```

### 7. 3D-Printed Parts (already printed ✅)

#### Unit 2 Parts List
| Filename | Qty | Purpose |
|---|:---:|---|
| BRKT_motor1_x3.stl | 3 | Motor bracket (base) |
| BRKT_motor2_x12.stl | 12 | Motor bracket (legs) |
| BRKT_MPU6050_x1.stl | 1 | IMU sensor bracket |
| BRKT_PCBbord_x1.stl | 1 | PCB bracket |
| CORNER_CUBEx8.stl | 8 | Cube-shaped corner spacers |
| FRAME_bord_x3.stl | 3 | Frame (PCB/sensor side) |
| FRAME_motor_x3.stl | 3 | Frame (motor side) |
| wheel_x3.stl | 3 | Reaction wheels |

---

## 💰 Estimated Cost

| Category | Estimate |
|---|---:|
| Microcontroller (Pico W) + Sensors | ¥1,900 |
| Motor modules (built-in driver) ×3 | ¥2,400–6,000 |
| Battery & charger | ¥5,000–8,500 |
| Power circuit parts (7805, caps, resistors) | ¥100 |
| PCB (board house order) | ¥500–1,000 |
| Connectors & wire | ¥1,000 |
| Screws & spacers | ¥1,500 |
| Bluetooth module | ¥0–800 |
| **Total (estimate)** | **¥12,400 – ¥19,800** |

> ※ Excludes 3D-printed parts (already printed ✅), tools, soldering iron, etc.
> ※ The biggest cost drivers are the motors and the battery.

---

## 🔍 Items to Verify (Next Steps)

### Highest Priority
1. **✅ Schematic analysis complete** — Motors confirmed as "integrated 8-pin modules with built-in driver & encoder"
2. **Source the motors** — Find the same type of 8-pin motor module
   - Search AliExpress/Taobao for "DC motor built-in driver encoder 8pin 12V"
   - Look for motors similar to the Nidec motor mentioned on imo Lab.'s blog
   - Or purchase the ¥800 recipe from [BOOTH](https://booth.pm/ja/items/5992975) for the exact part numbers
3. **Check motor dimensions from 3D model** — Verify bracket mounting hole diameter and pitch
   - Open `D:\3軸姿勢制御\2号機_Pico版\3Dモデル\Assy.step` in CAD to check
4. **Battery size** — Confirm it fits inside the PCB bracket

### Consider Purchasing imo Lab.'s Recipe
- Available on [BOOTH](https://booth.pm/ja/items/5992975) for ¥800 — complete design dataset
- Likely includes the exact BOM and assembly instructions

### Nidec 24H Motor Reference Resources
- [Arduino Forum: Nidec 24H055M020 reverse-engineering](https://forum.arduino.cc/t/nidec-24h055m020-operation-solved-mostly/1429057) — Pinout analysis
- [GitHub: Nidec 24H control library](https://github.com/gcharles81/Nidec_24H_motor_control) — Arduino code example
- [YouTube: Nidec 24H wiring tutorial](https://www.youtube.com/watch?v=ZOyGFHkPrV4) — Wiring walkthrough
- [Arduino Forum: Self Balancing + Nidec 24H](https://forum.arduino.cc/t/self-balancing-reaction-wheel-problems-with-nidec-24h-055m020/1139918) — Practical example

---

## 🛒 Shopping Checklist (with purchase links)

> A copy-paste-ready checklist for purchasing. Listed in priority order.

### Top Priority (long lead time)

- [ ] **Motor: Nidec 24H055M020 ×4** (3 used + 1 spare)
  - 🏪 [Amazon.co.jp RUOHARD](https://www.amazon.co.jp/dp/B0FV3JQVN5) — ~¥1,500/ea, ships in a few days
  - 🏪 [Amazon.co.jp MESKE](https://www.amazon.co.jp/dp/B0D28GHSK1) — ~¥1,500/ea
  - 🏪 [AliExpress (cheapest)](https://ja.aliexpress.com/item/1005005567692278.html) — ~¥750/ea, delivery 2–3 weeks
  - ⚠️ **Choose a D-cut shaft. Avoid helical gear shafts.**

- [ ] **PCB order** (Gerber data: ZIP the contents of `hardware/gerber/` and upload)
  - 🏪 [JLCPCB](https://jlcpcb.com/) — $2–5 + shipping, delivery 1–2 weeks
  - 🏪 [PCBGOGO](https://www.pcbgogo.jp/) — Japanese-language support available

- [ ] **LiPo 3S battery 11.1V 500–800 mAh ×1**
  - 🏪 [Amazon "3S 11.1V 500mAh Lipo"](https://www.amazon.co.jp/s?k=3S+11.1V+500mAh+Lipo)
  - ⚠️ Choose a size that fits the PCB bracket

- [ ] **LiPo balance charger (3S compatible) ×1**
  - 🏪 [Amazon "Lipo charger 3S"](https://www.amazon.co.jp/s?k=Lipo+%E5%85%85%E9%9B%BB%E5%99%A8+3S)

### Akizuki Denshi — Bulk Order (Japan only — international buyers: source equivalents locally)

- [ ] **Raspberry Pi Pico W ×1** — [Akizuki ¥1,240](https://akizukidenshi.com/catalog/g/g117947/)
- [ ] **Voltage regulator NJM7805FA ×1** — [Akizuki ¥60](https://akizukidenshi.com/catalog/g/g108678/)
- [ ] **MLCC 0.1 µF ×1** — Akizuki ¥10
- [ ] **Electrolytic capacitor 33 µF 25V ×1** — Akizuki ¥20
- [ ] **Carbon resistor 1.5 kΩ ×1** — Akizuki ¥10
- [ ] **Carbon resistor 470 Ω ×1** — Akizuki ¥10
- [ ] **Pin header 1×40 ×2** — Akizuki ¥50/strip
- [ ] **Pin socket 1×40 ×2** — Akizuki ¥80/strip
- [ ] **Slide switch ×1** — Akizuki ¥50~

### Amazon — Bulk Order

- [ ] **MPU6050 (GY-521) module** — [Amazon 5-pack ¥1,100](https://www.amazon.co.jp/dp/B07MPBMRWD)
- [ ] **Shaft hub / coupling 6 mm ×3** — [Amazon "shaft coupling 6mm"](https://www.amazon.co.jp/s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)
- [ ] **M3 bolt & nut set** — Amazon "M3 bolt nut set" ¥500~
- [ ] **M2 bolt & nut set** — Amazon "M2 bolt nut set" ¥300~
- [ ] **M3 flat-head screws ×40** — Amazon ¥300~ (for wheel balance)
- [ ] **AWG24 silicone wire** — Amazon ¥500~
- [ ] **Cable ties** — Amazon or dollar store

### Optional

- [ ] **imo Lab. recipe** — [BOOTH ¥800](https://booth.pm/ja/items/5992975) (exact part numbers & assembly instructions)

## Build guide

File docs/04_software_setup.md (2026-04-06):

# 💻 ソフトウェア環境セットアップガイド

> Arduino IDE と Processing IDE の環境構築手順

---

## 1. Arduino IDE セットアップ

### 1.1 インストール

1. [Arduino IDE 2.x](https://www.arduino.cc/en/software) をダウンロード・インストール

### 1.2 Raspberry Pi Pico W ボードの追加

1. Arduino IDE を起動
2. **File** → **Preferences** → **Additional boards manager URLs** に以下を追加:
   ```
   https://github.com/earlephilhower/arduino-pico/releases/download/global/package_rp2040_index.json
   ```
3. **Tools** → **Board** → **Boards Manager** で `pico` を検索
4. **Raspberry Pi Pico/RP2040** (by Earle F. Philhower) をインストール
5. ボード選択: **Tools** → **Board** → **Raspberry Pi Pico W**

### 1.3 ESP32 ボードの追加（1号機を使う場合）

1. **Preferences** → **Additional boards manager URLs** に追加:
   ```
   https://espressif.github.io/arduino-esp32/package_esp32_index.json
   ```
2. **Boards Manager** で `esp32` を検索・インストール
3. ボード選択: **ESP32 Dev Module**

### 1.4 ライブラリ

標準の `Wire.h` のみ使用（ESP32版）。

> ⚠️ **Pico W 版の追加ライブラリ:**
> - `SerialBT.h` — Bluetooth SPP 通信用のカスタムライブラリ（imo Lab. の頒布データに含まれる）
> - Pico W 内蔵 BT を使う場合は、このライブラリの代わりに `SerialBluetooth` 等の
>   Pico W 対応ライブラリへの差し替えが必要
> - Bluetooth を使わずに USB シリアルのみで運用する場合は、`SerialBT` 関連コードを
>   `Serial` に置き換えることで対応可能

### 1.5 ファームウェアの書き込み

**Pico W の場合:**
1. Pico W の **BOOTSEL** ボタンを押しながら USB 接続
2. Arduino IDE でポートを選択
3. `firmware/pico_w/3axis_control.ino` を開く
4. **Upload** ボタンでコンパイル＆書き込み

**ESP32 の場合:**
1. USB で接続（ドライバが自動認識されない場合は CP2102/CH340 ドライバをインストール）
2. Arduino IDE でポートを選択
3. `firmware/esp32/3axis_control.ino` を開く
4. **Upload** ボタン

### 1.6 シリアルモニタで動作確認

1. **Tools** → **Serial Monitor** を開く
2. ボーレート: **115200**
3. 正常なら `dt:`, `roll:`, `pitch:` 等のデータが流れる

---

## 2. Processing IDE セットアップ

Processing はPIDパラメータのリアルタイムチューニングGUIとして使用する。

### 2.1 インストール

1. [Processing 4.x](https://processing.org/download) をダウンロード・インストール

### 2.2 ライブラリの追加

1. Processing を起動
2. **Sketch** → **Import Library** → **Manage Libraries**
3. 以下を検索・インストール:
   - **ControlP5** — GUI コントロール（スライダー、テキストフィールド等）

> `processing.serial.*` は標準で含まれているため追加不要。

### 2.3 チューニングGUIの使い方

1. `processing/tuning_gui.pde` を Processing で開く
2. **COM ポート番号を修正** — ファイル内の `Serial.list()[X]` や `"COM4"` を自分の環境に合わせる
3. **Run** ボタンで起動
4. キューブと Bluetooth 接続した状態で:
   - スライダーで Kp / Ki / Kd / Ka / Kt を調整
   - リアルタイムで角度・角速度グラフを確認
   - 安定するパラメータを探る

### 2.4 Bluetooth 接続

1. PC の Bluetooth 設定で ESP32/Pico W をペアリング
2. 仮想 COM ポートが割り当てられる（例: COM4, COM5）
3. Processing の Serial ポートをその COM ポートに設定

---

## 3. トラブルシューティング

| 症状 | 対処法 |
|---|---|
| ボードが認識されない | USB ケーブルがデータ対応か確認（充電専用ケーブル不可） |
| コンパイルエラー | ボード選択が正しいか確認。Pico W 用コードに ESP32 ボードを選んでいないか |
| シリアルモニタに何も出ない | ボーレート 115200 か確認。リセットボタンを押す |
| Processing でポートが見つからない | Bluetooth ペアリング済みか確認。デバイスマネージャで COM ポート番号を確認 |
| IMU の値がおかしい | I2C 接続を確認（SDA/SCL の接続、プルアップ抵抗） |

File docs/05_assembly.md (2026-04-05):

# 🔧 組立手順ガイド

> 3軸姿勢制御モジュール（Self-Balancing Cube）の組立手順

---

## 全体の流れ

```
Step 1        Step 2        Step 3        Step 4        Step 5
リアクション → モーター   → フレーム   → 基板・      → 全体
ホイール作成   ブラケット   組立(3面)    センサー側    合体
              作成                      フレーム(3面)
```

---

## 必要な工具

| 工具 | 用途 |
|---|---|
| 精密ドライバーセット（+/-） | ネジ締め全般 |
| 六角レンチ（シャフトハブのイモネジ） | ホイール固定 |
| はんだごて + はんだ | 基板組立 |
| テスター（マルチメーター） | 通電確認、電圧測定 |
| ニッパー | 配線カット |
| ワイヤーストリッパー | 被覆剥き |
| ピンセット | 小部品取扱い |

---

## Step 1: リアクションホイールの作成

### 使用パーツ
- `wheel_x3.stl` × 3（3Dプリント済み）
- 金属製シャフトハブ（6mm径用）× 3
- M3 皿小ねじ + ナット（重量バランス調整用）

### 手順

1. **シャフトハブの取付け**
   - ホイール中心にシャフトハブをはめ込む
   - イモネジで仮固定（モーター取付後に本締め）

2. **重量バランス調整（後で実施でもOK）**
   - ホイール外周の穴にM3皿小ねじ + ナットを取付け
   - 全穴に均等に取付けるか、バランスを見ながら調整
   - 最終調整は倒立テスト時に実施

> ⚠️ ホイールの重量バランスが悪いと振動の原因になる。
> 3枚ともなるべく均一に作る。

---

## Step 2: モーターブラケットの作成

### 使用パーツ（1モーター分）
- `BRKT_motor1_x3.stl` × 1（ベース）
- `BRKT_motor2_x12.stl` × 4（脚）
- Nidec 24H モーター × 1
- M3 低頭ねじ × 4（モーター固定）
- M3 ボルト + ナット（ブラケット組立）

### 手順

1. **ベース部分をモーターに取付け**
   - 低頭ねじでモーターにブラケットベースを固定
   - ホイールとの隙間をなるべく確保するため低頭ねじ推奨

2. **脚の取付け**
   - 4本の脚をベースにビス止め
   - これを **3セット** 作成

3. **リアクションホイールの取付け**
   - モーターシャフトにホイールを差し込み
   - シャフトハブのイモネジを本締め
   - ホイールが自由に回転することを確認

> 💡 モーターの配線コネクタの向きに注意。後でフレームに組み込んだ際に
> 配線が取り回しやすい方向にしておく。

---

## Step 3: モーター側フレームの組立（3面）

### 使用パーツ
- `FRAME_motor_x3.stl` × 3
- `CORNER_CUBEx8.stl` × 8（のうち4個をこの段階で使用）
- M3 ボルト + ナット

### 手順

1. **フレームにモーターブラケットをビス止め**
   - 3枚のフレームそれぞれに Step 2 で作ったモーターユニットを固定

2. **キューブ型スペーサーで3面を連結**
   - フレームの四隅にキューブ型スペーサーを取付け
   - 3面を立方体の半分（モーター側）として組立て

> ⚠️ imo Lab. の経験談: ナットへのアクセスが悪い場合がある。
> インサートナット風のスペーサー形状を使うと組立が楽になる。

---

## Step 4: 基板・センサー側フレームの組立（3面）

### 使用パーツ
- `FRAME_bord_x3.stl` × 3
- `BRKT_MPU6050_x1.stl` × 1
- `BRKT_PCBbord_x1.stl` × 1
- 残りの `CORNER_CUBEx8.stl` × 4
- MPU6050 モジュール
- 基板（はんだ付け済み）
- M2 ボルト（MPU6050 固定用）
- M3 スペーサー（基板固定用）

### 手順

1. **MPU6050 ブラケットの作成**
   - ブラケットにMPU6050をM2ボルト+ナットで固定
   - 点倒立時にセンサーが水平になる向きに取付け

2. **基板ブラケットの作成**
   - ブラケットに基板をスペーサーで固定
   - バッテリーは基板の反対側にタイラップで固定予定

3. **基板側フレーム3面の組立**
   - 3枚のフレームをキューブ型スペーサーで連結
   - センサーブラケットと基板ブラケットをフレームにねじ止め

> 💡 **重心を中央に**: 点倒立時に重心バランスがなるべく中央に来るよう
> 基板とバッテリーの配置を工夫する。

---

## Step 5: 全体の合体

### 手順

1. **モーター側3面 + 基板側3面 を合体**
   - 残りのキューブ型スペーサーで6面を結合
   - すべてのビスを均等に締める

2. **配線**
   - モーター → 基板の8ピンコネクタに接続（[配線表](03_circuit.md)参照）
   - MPU6050 → I2C (SDA/SCL) 接続
   - バッテリー → 電源コネクタ

3. **バッテリーの搭載**
   - 基板ブラケットの裏側にタイラップで固定
   - 重心バランスを考慮した位置に配置

4. **最終確認**
   - [ ] 全ビスの締め付け確認
   - [ ] モーター配線の極性確認（**逆接厳禁！**）
   - [ ] ホイールが自由に回転するか確認（干渉がないか）
   - [ ] 通電テスト（テスターで5V出力確認）
   - [ ] I2Cスキャンでセンサー応答確認

---

## 完成後のチェックリスト

- [ ] キューブを手で持ち上げて振っても各部品がガタつかない
- [ ] ホイール3枚が指で軽く回せる（摩擦が小さい）
- [ ] モーター配線のコネクタがしっかり挿さっている
- [ ] バッテリーが固定されている
- [ ] 電源スイッチの動作確認
- [ ] 通電時にPico WのLEDが点灯する

> 次のステップ: [ソフトウェアセットアップ](04_software_setup.md) → [PIDチューニング](06_tuning.md)

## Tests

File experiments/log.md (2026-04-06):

# 📝 実験ログ

> Copilot CLI を活用した3軸姿勢制御モジュール制作の記録

---

## 2026-04-05: プロジェクト開始

### やったこと
- 参考設計（imo Lab.）のソースコード・回路図を分析
- 回路図からモーターが **Nidec 24H055M020**（ドライバ内蔵BLDC）であることを特定
- 完全な部品表（BOM）を作成
- 理論ドキュメント（物理数式）を作成
- 実験スケジュールを策定

### 使用ツール
- GitHub Copilot CLI: コード解析、BOM作成、理論ドキュメント執筆
- Web検索: モーター型番特定、購入先調査

### 次のステップ
- [x] 部品の発注（モーター、センサー、バッテリー等）
- [x] PCBの発注（ガーバーデータを JLCPCB に入稿）
- [ ] Arduino IDE / Processing IDE の環境構築

---

## 2026-04-06: 全部品の発注完了

### やったこと
- Copilot CLI を活用して BOM の全部品を調査・選定・発注

### 発注リスト

#### AliExpress（到着目安: 2-3週間）
| 部品 | 数量 | 価格 | 備考 |
|---|:---:|---:|---|
| CNHL MiniStar 650mAh 3S 70C LiPoバッテリー | 2個セット | ¥2,656 | XT30コネクタ、58×30×22mm、約70g |
| Nidec 24H055M020 モーター | 4個 | — | Dカット軸を選定。3個使用+予備1個 |

#### JLCPCB（到着目安: 1-2週間）
| 部品 | 数量 | 価格 | 備考 |
|---|:---:|---:|---|
| カスタムPCB基板 | 5枚 | $2〜5+送料 | hardware/gerber/ のデータで発注。2層、1.6mm厚 |

#### Amazon（到着目安: 数日）
| 部品 | 型番/検索キーワード | 数量 | 備考 |
|---|---|:---:|---|
| LiPoバランス充電器 | HotRC B3（2S/3S対応・10W版） | 1 | 充電電流0.8A、650mAhに最適 |
| 6軸IMUセンサ | MPU6050 GY-521 モジュール | 1 | I2C接続 |
| シャフトハブ 6mm | フランジカップリング 6mm（2個入） | 2セット | 計4個（3個使用+予備1個） |
| M3ボルト・ナットセット | サムコス 皿頭小ネジ M3 340個セット | 1 | モーターマウント＋ホイールバランス用 |
| M2ボルト・ナットセット | ナベ頭小ねじ M2 662個セット | 1 | MPU6050固定用 |
| シリコンワイヤー | Striveday 24AWG 箱入りセット | 1 | 配線用 |

#### 秋月電子通商（到着目安: 数日）
| 部品 | 型番 | 数量 | 価格 |
|---|---|:---:|-----:|
| Raspberry Pi Pico W | SC0918 | 1 | ¥1,240 |
| 三端子レギュレータ | NJM7805FA (TO-220F) | 1 | ¥60 |
| 積層セラミックコンデンサ 0.1µF 50V | RDER71H104K0P1H03B | 1袋(10個) | ¥100 |
| 電解コンデンサ 33µF 25V | ECASD41E336M040KA0 | 1 | ¥30 |
| カーボン抵抗 1.5kΩ 1/4W | CF25J1K5B | 1袋(100本) | ¥170 |
| カーボン抵抗 470Ω 1/4W | CF25J470RB | 1袋(100本) | ¥200 |
| ピンヘッダ 1×40 | PH-1x40SG | 2 | ¥35/本 |
| ピンソケット 1×40 | 分割ロングピンソケット(メス) | 2 | ¥80/本 |
| スライドスイッチ | SS12D01G4 (1回路2接点) | 1 | ¥30 |

### 概算総額: 約 ¥15,000〜18,000

### 使用ツール
- GitHub Copilot CLI: 部品選定、在庫調査、購入先比較、ガーバーZIP作成

### Next Action
- [ ] 届いた部品の検品・動作確認（特にモーターのシャフト形状）
- [ ] Arduino IDE のセットアップ（[docs/04_software_setup.md](../docs/04_software_setup.md) 参照）
- [ ] Processing IDE のセットアップ（PIDチューニングGUI用）
- [ ] 基板へのはんだ付け（[docs/03_circuit.md](../docs/03_circuit.md) 参照）
- [ ] リアクションホイールの組立（[docs/05_assembly.md](../docs/05_assembly.md) Step 1）
- [ ] モーターブラケットの組立（Step 2）
- [ ] 1軸での倒立テスト → PIDチューニング（[docs/06_tuning.md](../docs/06_tuning.md)）

---

*（以降、実験のたびに日付とともに追記していく）*

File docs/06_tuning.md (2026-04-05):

# 🎛️ PIDチューニングガイド

> リアルタイムでPIDパラメータを調整し、安定した倒立を実現する

---

## 概要

PIDチューニングは **試行錯誤のプロセス** である。
理論的な初期値から始めて、実機の挙動を見ながら調整していく。

```
初期値設定 → 1軸テスト（辺倒立）→ 3軸テスト（点倒立）→ 微調整
              ↑                      ↑
              └── ゲイン調整 ────────┘
```

---

## 1. チューニング環境の準備

### 必要なもの
- PC（Processing IDE インストール済み → [セットアップ](04_software_setup.md)）
- Bluetooth 接続（PC ↔ キューブ）
- 広くて平らな場所（テーブルの上など）
- キューブを支える手（最初は手で支えながら調整）

### Processing GUI の起動

1. `processing/tuning_gui.pde` を Processing で開く
2. COM ポート番号を自分の環境に修正
3. Run ボタンで起動
4. Bluetooth ペアリング済みのキューブの電源を入れる

---

## 2. PIDパラメータの役割

### パラメータ一覧

| パラメータ | 記号 | 役割 | 大きくすると | 小さくすると |
|---|---|---|---|---|
| **比例ゲイン** | Kp | 偏差に比例した修正力 | 応答が速くなるが振動しやすい | 応答が遅くなる |
| **積分ゲイン** | Ki | 定常偏差の除去 | 一方向に傾く問題が解消 | 定常偏差が残る |
| **微分ゲイン** | Kd | 振動の抑制（ダンピング） | 振動が収まるがノイズに敏感 | 振動が収まりにくい |
| **角度ゲイン** | Ka | 角度→角速度変換の感度 | 角度偏差に敏感に反応 | 鈍い反応 |
| **目標補正** | Kt | 目標角度の自動補正速度 | バランス点を速く学習 | ゆっくり学習 |

### 直感的なイメージ

```
Kp が大きすぎ: ブルブル震える（振動）
Kp が小さすぎ: ゆっくり倒れる（応答不足）

Ki が大きすぎ: 大きくうねる（オーバーシュート）
Ki が小さすぎ: 一方向に少し傾いたまま

Kd が大きすぎ: カクカクした動き（ノイズ増幅）
Kd が小さすぎ: 振動が止まらない
```

---

## 3. チューニング手順

### Phase 1: 1軸テスト（辺倒立）

キューブを **辺（稜線）** の上に置いて、1モーターだけで倒立させる。

> 💡 3軸同時に調整するのは難しいので、まず1軸で基本的なゲインを見つける。

#### 3.1 初期値の設定

コードのデフォルト値を出発点にする:

| パラメータ | 1号機初期値 | 2号機初期値 | まず試す値 |
|---|:---:|:---:|:---:|
| Kp | 60.0 | 32.0 | 30.0 |
| Ki | 12.0 | 45.0 | 30.0 |
| Kd | 90.0 | 95.0 | 90.0 |
| Ka | 5.0 | 5.5 | 5.0 |
| Kt | 1.0 | 1.3 | 1.0 |

#### 3.2 Kp の調整（最初にやる）

1. Ki = 0, Kd = 0 に設定（P制御のみ）
2. キューブを辺の上に手で支えて置く
3. Kp を少しずつ上げていく
4. **倒れる方向に軽くモーターが反応する** のを確認
5. 反応が見えたら Kp を上げて、軽く手を離してみる
6. 振動するなら Kp が高すぎ、倒れるなら低すぎ

#### 3.3 Kd の調整（次にやる）

1. Kp はそのまま、Kd を少しずつ上げる
2. 振動が抑えられていくのを確認
3. Kd が大きすぎるとカクカクした動きになる
4. **振動が収まりつつ、まだ応答がある** バランスを探す

#### 3.4 Ki の調整（最後にやる）

1. Kp, Kd はそのまま、Ki を少しずつ上げる
2. 一方向に傾く（定常偏差）が解消されるのを確認
3. Ki が大きすぎるとゆっくり大きく揺れる（積分ワインドアップ）

#### 3.5 1軸倒立の達成

- 手を離して **数秒以上** 辺の上で倒立できたらOK
- 安定しない場合は Kp/Kd の比率を変えてみる

### Phase 2: 3軸テスト（点倒立）

1軸が安定したら、角（頂点）の上に置いて3軸制御に挑戦。

#### 3.6 Roll/Pitch 調整値の設定

```
ROLL_ADJUST（rollAdj）: Roll方向のバランスオフセット
PITCH_ADJUST（pitchAdj）: Pitch方向のバランスオフセット
```

- キューブを角の上に置いて、どちらに倒れるか観察
- 倒れる方向の ADJUST 値を少し変更して重心ズレを補正
- Processing GUI のスライダーでリアルタイム調整

#### 3.7 Yaw 軸の追加（2号機のみ）

1. Roll/Pitch がある程度安定したら Kz を少しずつ上げる
2. 点倒立中に z 軸まわりの回転が抑制されるのを確認
3. yawAdj でYaw方向のトリム調整

---

## 4. トラブルシューティング

| 症状 | 考えられる原因 | 対処法 |
|---|---|---|
| まったく反応しない | モーター配線ミス、SS信号LOW | 配線確認、`vertical` フラグ確認 |
| 激しく振動する | Kp が高すぎ | Kp を下げる、Kd を上げる |
| ゆっくり倒れる | Kp が低すぎ | Kp を上げる |
| 一方向に傾いたまま | 重心ズレ、Ki不足 | ADJUST値を調整、Ki を上げる |
| 大きくうねる | Ki が高すぎ | Ki を下げる |
| カクカクした動き | Kd が高すぎ | Kd を下げる |
| 1軸はOKだが3軸で不安定 | ミキシングの問題 | モーター方向の確認、配線の入替 |
| ホイールが一方向に加速し続ける | 積分ワインドアップ | I項にconstrain制限を確認 |
| すぐに vertical=0 になる | 閾値が厳しすぎ | コード内の角度閾値を緩める |

---

## 5. チューニングのコツ

### やってはいけないこと
- ❌ 複数のパラメータを同時に変える
- ❌ 大きな値をいきなり入れる
- ❌ 制御が不安定なまま手を離す

### やるべきこと
- ✅ 1つずつパラメータを変える
- ✅ 少しずつ（10〜20%刻みで）変える
- ✅ Processing GUI のグラフで角度/角速度を観察する
- ✅ 安定したパラメータはメモしておく
- ✅ 最初は手で支えながら調整する

### パラメータの保存

安定したパラメータが見つかったら、ファームウェアのデフォルト値として書き込む:

```cpp
// firmware/pico_w/3axis_control.ino の冒頭
#define _Kt 1.3    // ← ここに安定した値を書き込む
#define _Ka 5.5
#define _Kp 32.0
#define _Ki 45.0
#define _Kd 95.0
```

---

## 6. 重量バランスの微調整

PIDチューニングだけでは解決できない問題は、物理的な重量バランスで対処する。

### ホイールのバランス

- ホイール外周のボルト穴に M3 ボルト＋ナットを追加/除去
- 3枚のホイールの重量をなるべく均一にする
- 回転時の振動が減るよう調整

### 筐体のバランス

- バッテリーの位置を微調整（重心が角の真上に来るように）
- 配線の取り回しも重量バランスに影響する
- ROLL_ADJUST / PITCH_ADJUST で補正しきれない場合は物理調整

> 次のステップ: 安定した点倒立を達成したら [実験ログ](../experiments/log.md) に記録しよう！

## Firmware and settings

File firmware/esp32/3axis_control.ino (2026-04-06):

//2024/08/10
//3軸姿勢制御モジュール Ver1.0.0
//imo Lab. https://Garchiving.com
//https://garchiving.com/summary-of-self-balancing-cube/

#include <Wire.h>
#include "BluetoothSerial.h"

#define _Ks 1.0
#define _Kp_angle 5.0
#define _Kp 60.0
#define _Ki 12.0
#define _Kd 90.0

#define _ROLL_ADJUST -5.2
#define _PITCH_ADJUST 0.5

#define ROLL 0
#define PITCH 1
#define YAW 2

#define PIN_PWM_CTR 25
#define PIN_BRAKE_CTR 17
#define PIN_DIRECTION_CTR 13

#define PIN_PWM_RH 26
#define PIN_BRAKE_RH 18
#define PIN_DIRECTION_RH 14

#define PIN_PWM_LH 27
#define PIN_BRAKE_LH 19
#define PIN_DIRECTION_LH 16

BluetoothSerial SerialBT;

int16_t voltage_mV, current_mA;
uint32_t currentTime, mainLoopTimer, BluetoothTimer, dt, dtTime;

int16_t PID[2];

bool vertical;

float TargetOmega[2], TargetAngle[2];
float P[2], preP[2], I[2], D[2];
float Ks, Kp_angle, Kp, Ki, Kd;
float ROLL_ADJUST, PITCH_ADJUST;

uint16_t angCalibration;
int32_t accCal[3];
int32_t gyroCal[3];
typedef union {
  struct {
    int32_t X, Y, Z;
  } B32;
  struct {
    int16_t XL;
    int16_t X;
    int16_t YL;
    int16_t Y;
    int16_t ZL;
    int16_t Z;
  } B16;
} TYPE;

TYPE accRaw, accRawLPF;
TYPE gyroRaw, gyroRawLPF;
TYPE Vg = { 0, 0, 4096 * 65536 };
TYPE Vg0;
float angle[3];

void setup() {
  Serial.begin(115200);
  SerialBT.begin("ESP32-CUBE");

  Wire.begin();
  Wire.setClock(400000);
  delay(500);

  pinMode(PIN_BRAKE_CTR, OUTPUT);
  pinMode(PIN_BRAKE_RH, OUTPUT);
  pinMode(PIN_BRAKE_LH, OUTPUT);

  pinMode(PIN_DIRECTION_CTR, OUTPUT);
  pinMode(PIN_DIRECTION_RH, OUTPUT);
  pinMode(PIN_DIRECTION_LH, OUTPUT);

  digitalWrite(PIN_BRAKE_CTR, LOW);
  digitalWrite(PIN_BRAKE_RH, LOW);
  digitalWrite(PIN_BRAKE_LH, LOW);

  digitalWrite(PIN_DIRECTION_CTR, HIGH);
  digitalWrite(PIN_DIRECTION_RH, HIGH);
  digitalWrite(PIN_DIRECTION_LH, HIGH);

  ledcAttach(PIN_PWM_CTR, 20000, 8);
  ledcWrite(PIN_PWM_CTR, 255);

  ledcAttach(PIN_PWM_RH, 20000, 8);
  ledcWrite(PIN_PWM_RH, 255);

  ledcAttach(PIN_PWM_LH, 20000, 8);
  ledcWrite(PIN_PWM_LH, 255);

  setupINA219();
  setupMPU6050();
  readMPU6050();
  Vg.B16.X = accRaw.B16.X;
  Vg.B16.Y = accRaw.B16.Y;
  Vg.B16.Z = accRaw.B16.Z;
  accRawLPF.B16.X = accRaw.B16.X;
  accRawLPF.B16.Y = accRaw.B16.Y;
  accRawLPF.B16.Z = accRaw.B16.Z;

  Ks = _Ks;
  Kp_angle = _Kp_angle;
  Kp = _Kp;
  Ki = _Ki;
  Kd = _Kd;
  ROLL_ADJUST = _ROLL_ADJUST;
  PITCH_ADJUST = _PITCH_ADJUST;

  currentTime = micros();
  mainLoopTimer = currentTime;
}

void loop() {
  currentTime = micros();

  if (currentTime - mainLoopTimer >= 10000) {  //10ms
    mainLoopTimer = micros();

    readINA219();    //1200us
    computeAngle();  //524us
    angle[ROLL] += ROLL_ADJUST;
    angle[PITCH] += PITCH_ADJUST;

    if (abs(angle[ROLL]) < 1.00 && abs(angle[PITCH]) < 1.00) vertical = 1;
    if (abs(angle[ROLL]) > 7.0 || abs(angle[PITCH]) > 7.00) vertical = 0;

    PID_COMP();  //20us

    Serial.print("dt:");
    Serial.print((float)dt, 0);
    Serial.print(",");
    Serial.print("Ks:");
    Serial.print((float)Ks, 1);
    Serial.print(",");
    Serial.print("Kp:");
    Serial.print((float)Kp, 1);
    Serial.print(",");
    Serial.print("Ki:");
    Serial.print((float)Ki, 1);
    Serial.print(",");
    Serial.print("Kd:");
    Serial.print((float)Kd, 1);
    Serial.print(",");
    Serial.print("roll:");
    Serial.print((float)ROLL_ADJUST, 1);
    Serial.print(",");
    Serial.print("pitch:");
    Serial.print((float)PITCH_ADJUST, 1);
    Serial.print("\n");

    dt = micros() - mainLoopTimer;
  }

  if (currentTime - BluetoothTimer >= 0) {  //120us
    BluetoothTimer = micros();
    BlueToothCom();
  }
}

inline void PID_COMP() {
  if (vertical) {
    //角速度PID
    //目標値補正
    TargetAngle[ROLL] += 0.01 * Ks * (TargetAngle[ROLL] - angle[ROLL]);
    TargetAngle[ROLL] = constrain(TargetAngle[ROLL], -19, 19);

    TargetAngle[PITCH] += 0.01 * Ks * (TargetAngle[PITCH] - angle[PITCH]);
    TargetAngle[PITCH] = constrain(TargetAngle[PITCH], -19, 19);

    //目標角速度
    TargetOmega[ROLL] = Kp_angle * (TargetAngle[ROLL] - angle[ROLL]);
    P[ROLL] = TargetOmega[ROLL] - (gyroRawLPF.B16.X * 0.0152587890625);
    I[ROLL] += P[ROLL] * 0.01;
    I[ROLL] = constrain(I[ROLL], -3, 3);
    D[ROLL] = (gyroRawLPF.B16.X * 0.0152587890625) - preP[ROLL];
    preP[ROLL] = (gyroRawLPF.B16.X * 0.0152587890625);
    PID[ROLL] = Kp * P[ROLL] + Ki * I[ROLL] - Kd * D[ROLL];

    TargetOmega[PITCH] = Kp_angle * (TargetAngle[PITCH] - angle[PITCH]);
    P[PITCH] = TargetOmega[PITCH] - (gyroRawLPF.B16.Y * 0.0152587890625);
    I[PITCH] += P[PITCH] * 0.01;
    I[PITCH] = constrain(I[PITCH], -3, 3);
    D[PITCH] = (gyroRawLPF.B16.Y * 0.0152587890625) - preP[PITCH];
    preP[PITCH] = (gyroRawLPF.B16.Y * 0.0152587890625);
    PID[PITCH] = Kp * P[PITCH] + Ki * I[PITCH] - Kd * D[PITCH];

    PID[ROLL] = constrain(PID[ROLL], -255, 255);
    PID[PITCH] = constrain(PID[PITCH], -255, 255);
    motorControl_CTR(PID[ROLL]);
    motorControl_RH(0.866 * PID[PITCH] + 0.5 * PID[ROLL]);
    motorControl_LH(0.866 * PID[PITCH] - 0.5 * PID[ROLL]);
  } else {
    digitalWrite(PIN_BRAKE_CTR, LOW);
    digitalWrite(PIN_BRAKE_RH, LOW);
    digitalWrite(PIN_BRAKE_LH, LOW);

    I[ROLL] = 0;
    TargetOmega[ROLL] = 0;
    TargetAngle[ROLL] = 0;
    PID[ROLL] = 0;

    I[PITCH] = 0;
    TargetOmega[PITCH] = 0;
    TargetAngle[PITCH] = 0;
    PID[PITCH] = 0;
  }
}

inline void motorControl_CTR(int16_t val) {
  bool motorDir = 1;
  if (val > 0) motorDir = 0;
  if (val < 0) motorDir = 1;

  digitalWrite(PIN_BRAKE_CTR, HIGH);
  digitalWrite(PIN_DIRECTION_CTR, motorDir);
  ledcWrite(PIN_PWM_CTR, 255 - abs(val));
}

inline void motorControl_RH(int16_t val) {
  bool motorDir = 1;
  if (val > 0) motorDir = 1;
  if (val < 0) motorDir = 0;

  digitalWrite(PIN_BRAKE_RH, HIGH);
  digitalWrite(PIN_DIRECTION_RH, motorDir);
  ledcWrite(PIN_PWM_RH, 255 - abs(val));
}

inline void motorControl_LH(int16_t val) {
  bool motorDir = 1;
  if (val > 0) motorDir = 0;
  if (val < 0) motorDir = 1;

  digitalWrite(PIN_BRAKE_LH, HIGH);
  digitalWrite(PIN_DIRECTION_LH, motorDir);
  ledcWrite(PIN_PWM_LH, 255 - abs(val));
}

// ****************************************************************
// *** MPU6050 値読み取り ***//580us
// ****************************************************************
inline void readMPU6050() {
  Wire.beginTransmission(0x68);  //MPU-6050 デバイスアドレス
  Wire.write(0x3B);
  Wire.endTransmission();
  Wire.requestFrom(0x68, 14);

  while (Wire.available() < 14) {}
  accRaw.B16.X = Wire.read() << 8 | Wire.read();
  accRaw.B16.Y = Wire.read() << 8 | Wire.read();
  accRaw.B16.Z = Wire.read() << 8 | Wire.read();
  int16_t temperature = Wire.read() << 8 | Wire.read();
  gyroRaw.B16.X = Wire.read() << 8 | Wire.read();
  gyroRaw.B16.Y = Wire.read() << 8 | Wire.read();
  gyroRaw.B16.Z = Wire.read() << 8 | Wire.read();

  if (angCalibration == 2048) {
    accRaw.B16.X -= accCal[0];
    accRaw.B16.Y -= accCal[1];
    accRaw.B16.Z -= accCal[2];
    gyroRaw.B16.X -= gyroCal[0];
    gyroRaw.B16.Y -= gyroCal[1];
    gyroRaw.B16.Z -= gyroCal[2];
  }

  accRawLPF.B32.X += (accRaw.B32.X - accRawLPF.B32.X) >> 2;
  accRawLPF.B32.Y += (accRaw.B32.Y - accRawLPF.B32.Y) >> 2;
  accRawLPF.B32.Z += (accRaw.B32.Z - accRawLPF.B32.Z) >> 2;
  gyroRawLPF.B32.X += (gyroRaw.B32.X - gyroRawLPF.B32.X) >> 2;
  gyroRawLPF.B32.Y += (gyroRaw.B32.Y - gyroRawLPF.B32.Y) >> 2;
  gyroRawLPF.B32.Z += (gyroRaw.B32.Z - gyroRawLPF.B32.Z) >> 2;
}

// ****************************************************************
// *** 姿勢角度算出 *** UNO:1050ms  ESP32:524us
// ****************************************************************
inline void computeAngle() {
  static uint32_t angTimer;
  uint32_t AttTime = micros();
  float dt2 = (AttTime - angTimer) * 0.000001;  //loop[s]
  float scale = 17.45329252 * dt2;              //(1/LSB)*PI*65536 = 17.45329252=>rad/s*65536
  angTimer = AttTime;

  readMPU6050();

  int32_t _sinX = gyroRaw.B16.X * scale;
  int32_t _sinY = gyroRaw.B16.Y * scale;
  int32_t _sinZ = gyroRaw.B16.Z * scale;

  Vg0.B32.X = Vg.B32.X + Vg.B16.Y * _sinZ - Vg.B16.Z * _sinY;
  Vg0.B32.Y = -Vg.B16.X * _sinZ + Vg.B32.Y + Vg.B16.Z * _sinX;
  Vg0.B32.Z = Vg.B16.X * _sinY - Vg.B16.Y * _sinX + Vg.B32.Z;

  Vg.B32.X = Vg0.B32.X;
  Vg.B32.Y = Vg0.B32.Y;
  Vg.B32.Z = Vg0.B32.Z;

  Vg.B32.X += (accRawLPF.B32.X - Vg.B32.X) >> 4;
  Vg.B32.Y += (accRawLPF.B32.Y - Vg.B32.Y) >> 4;
  Vg.B32.Z += (accRawLPF.B32.Z - Vg.B32.Z) >> 4;

  angle[ROLL] = _atan2(Vg.B16.Y, Vg.B16.Z) * 0.01;
  angle[PITCH] = -_atan2(Vg.B16.X, sqrt((int32_t)Vg.B16.Y * Vg.B16.Y + (int32_t)Vg.B16.Z * Vg.B16.Z)) * 0.01;
  angle[YAW] += -1 * gyroRaw.B16.Z * 0.0152587890625 * dt2;  //1/LSB
}

// ****************************************************************
// *** MPU6050 初期設定 ***
// ****************************************************************
void setupMPU6050() {
  //内部クロック8MHz
  Wire.beginTransmission(0x68);  //MPU6050デバイスアドレス
  Wire.write(0x6B);
  Wire.write(0x00);
  Wire.endTransmission();
  //加速度センサー
  Wire.beginTransmission(0x68);
  Wire.write(0x1C);
  Wire.write(0x10);  //±8G LSB:4096
  Wire.endTransmission();
  //ジャイロ
  Wire.beginTransmission(0x68);
  Wire.write(0x1B);
  Wire.write(0x08);  //500deg/s LSB:65.536
  Wire.endTransmission();
  //DigitalLPF
  Wire.beginTransmission(0x68);
  Wire.write(0x1A);
  Wire.write(0x05);  //≒43Hz 4.9ms遅れ
  Wire.endTransmission();

  for (angCalibration = 0; angCalibration < 2048; angCalibration++) {
    readMPU6050();
    delay(1);
    accCal[0] += accRaw.B16.X;
    accCal[1] += accRaw.B16.Y;
    accCal[2] += accRaw.B16.Z;
    gyroCal[0] += gyroRaw.B16.X;
    gyroCal[1] += gyroRaw.B16.Y;
    gyroCal[2] += gyroRaw.B16.Z;
  }
  accCal[0] /= 2048;
  accCal[1] /= 2048;
  accCal[2] = (accCal[2] / 2048) - 4096;
  gyroCal[0] /= 2048;
  gyroCal[1] /= 2048;
  gyroCal[2] /= 2048;

  //Manual Calibration
  //センサー水平
  //accCal[0] = 75;
  //accCal[1] = 88;
  //accCal[2] = -690;
  //gyroCal[0] = -52;
  //gyroCal[1] = 107;
  //gyroCal[2] = 47;

  //CUBE用（3軸用）
  accCal[0] += 1672;
  accCal[1] += -2896;
  accCal[2] += 1731;

  //CUBE用（2軸用）
  //accCal[0] += 1672;
  //accCal[1] += 2896;
  //accCal[2] += 1731;
}

// ****************************************************************
// *** INA219 読み取り ***
// ****************************************************************
inline void readINA219() {
  uint16_t busvoltage_raw, shuntvoltage_raw;
  int16_t busvoltage_mV, shuntvoltage_mV;

  Wire.beginTransmission(0x40);  // デバイスアドレス
  Wire.write(0x02);              // busvoltage_mV_mV_mV_mV_mVレジスタ
  Wire.endTransmission();
  Wire.requestFrom(0x40, 16);
  while (Wire.available() < 16) {};
  busvoltage_raw = Wire.read() << 8 | Wire.read();
  busvoltage_mV = (int16_t)((busvoltage_raw >> 3) * 4);  // mV

  Wire.beginTransmission(0x40);  // デバイスアドレス
  Wire.write(0x01);              // Shuntvoltage_mV_mV_mV_mVレジスタ
  Wire.endTransmission();
  Wire.requestFrom(0x40, 16);
  while (Wire.available() < 16) {};
  shuntvoltage_raw = Wire.read() << 8 | Wire.read();
  shuntvoltage_mV = (int16_t)(shuntvoltage_raw)*0.01;  // *0.01[mV]  // *10[uV]
  current_mA = (int16_t)(shuntvoltage_raw)*0.1;        //I=V/R=V/0.1=V*10

  voltage_mV = busvoltage_mV + shuntvoltage_mV;  // mV
}

// ****************************************************************
// *** INA219 初期設定 ***
// ****************************************************************
void setupINA219() {
  int16_t config_value = 0x399F;  //INA219 デフォルト
  Wire.beginTransmission(0x40);   //INA219 デバイスアドレス
  Wire.write(0x00);               //configアドレス
  Wire.write((config_value >> 8) & 0xFF);
  Wire.write(config_value & 0xFF);
  Wire.endTransmission();
}

// ********************************************************************************
// * atan2 近似式
// ********************************************************************************
inline int16_t _atan2(int16_t _y, int16_t _x) {
  int16_t x = abs(_x);
  int16_t y = abs(_y);
  float z;
  bool c;

  c = y < x;
  if (c) z = (float)y / x;
  else z = (float)x / y;

  int16_t a;
  //a = z * (-1556 * z + 6072);                     //2次曲線近似
  //a = z * (z * (-448 * z - 954) + 5894);          //3次曲線近似
  a = z * (z * (z * (829 * z - 2011) - 58) + 5741);  //4次曲線近似

  if (c) {
    if (_x > 0) {
      if (_y < 0) a *= -1;
    }
    if (_x < 0) {
      if (_y > 0) a = 18000 - a;
      if (_y < 0) a = a - 18000;
    }
  }

  if (!c) {
    if (_x > 0) {
      if (_y > 0) a = 9000 - a;
      if (_y < 0) a = a - 9000;
    }
    if (_x < 0) {
      if (_y > 0) a = a + 9000;
      if (_y < 0) a = -a - 9000;
    }
  }
  return a;
}

// ********************************************************************************
// * Bluetoothシリアル（SPP）
// ********************************************************************************
void BlueToothCom() {
  uint8_t inByteCnt = 15;
  uint8_t outByteCnt = 24;

  if (SerialBT.available() == inByteCnt) {
    byte inBuf[inByteCnt];  //受信
    SerialBT.readBytes(inBuf, inByteCnt);

    if (inBuf[0] == 's' || inBuf[0] == 'g') {  //送信
      byte outBuf[outByteCnt];
      outBuf[0] = 's';                                // 1 スタートビット
      outBuf[1] = (int16_t)accRawLPF.B16.X >> 8;      // 2
      outBuf[2] = (int16_t)accRawLPF.B16.X & 0xFF;    // 3
      outBuf[3] = (int16_t)accRawLPF.B16.Y >> 8;      // 4
      outBuf[4] = (int16_t)accRawLPF.B16.Y & 0xFF;    // 5
      outBuf[5] = (int16_t)accRawLPF.B16.Z >> 8;      // 6
      outBuf[6] = (int16_t)accRawLPF.B16.Z & 0xFF;    // 7
      outBuf[7] = (int16_t)gyroRawLPF.B16.X >> 8;     // 8
      outBuf[8] = (int16_t)gyroRawLPF.B16.X & 0xFF;   // 9
      outBuf[9] = (int16_t)gyroRawLPF.B16.Y >> 8;     //10
      outBuf[10] = (int16_t)gyroRawLPF.B16.Y & 0xFF;  //11
      outBuf[11] = (int16_t)gyroRawLPF.B16.Z >> 8;    //12
      outBuf[12] = (int16_t)gyroRawLPF.B16.Z & 0xFF;  //13
      outBuf[13] = (int16_t)(angle[0] * 100) >> 8;    //14
      outBuf[14] = (int16_t)(angle[0] * 100) & 0xFF;  //15
      outBuf[15] = (int16_t)(angle[1] * 100) >> 8;    //16
      outBuf[16] = (int16_t)(angle[1] * 100) & 0xFF;  //17
      outBuf[17] = (int16_t)(angle[2] * 100) >> 8;    //18
      outBuf[18] = (int16_t)(angle[2] * 100) & 0xFF;  //19
      outBuf[19] = (int16_t)voltage_mV >> 8;          // 20
      outBuf[20] = (int16_t)voltage_mV & 0xFF;        // 21
      outBuf[21] = (int16_t)current_mA >> 8;          // 22
      outBuf[22] = (int16_t)current_mA & 0xFF;        // 23
      outBuf[23] = 'e';                               //24 end bit
      SerialBT.write(outBuf, outByteCnt);

      if (inBuf[0] == 's') {
        int16_t raw[7];
        raw[0] = ((int16_t)inBuf[1] << 8) + (inBuf[2] & 0xff);
        raw[1] = ((int16_t)inBuf[3] << 8) + (inBuf[4] & 0xff);
        raw[2] = ((int16_t)inBuf[5] << 8) + (inBuf[6] & 0xff);
        raw[3] = ((int16_t)inBuf[7] << 8) + (inBuf[8] & 0xff);
        raw[4] = ((int16_t)inBuf[9] << 8) + (inBuf[10] & 0xff);

        raw[5] = ((int16_t)inBuf[11] << 8) + (inBuf[12] & 0xff);
        raw[6] = ((int16_t)inBuf[13] << 8) + (inBuf[14] & 0xff);

        Ks = raw[0] * 0.1;
        Kp = raw[1] * 0.1;
        Ki = raw[2] * 0.1;
        Kd = raw[3] * 0.1;
        Kp_angle = raw[4] * 0.1;
        ROLL_ADJUST = raw[5] * 0.1;
        PITCH_ADJUST = raw[6] * 0.1;
      }

    } else {  //inBuf[0] == 's'
      while (SerialBT.available() > 0) SerialBT.read();
      //Serial.println("missmatch");
    }
  }  //Serial.available() == inByteCnt

  if (SerialBT.available() > inByteCnt) {  //オーバーフロー
    while (SerialBT.available() > 0) SerialBT.read();
    //Serial.println("overfllow");
  }
}

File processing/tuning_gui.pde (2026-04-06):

import processing.serial.*;
import controlP5.*;

Serial myPort;

ControlP5   cp5;
Chart       dtChart, AngleChart;
Slider      KtSlider, KaSlider, KpSlider, KiSlider, KdSlider, KzSlider, rollAdjSlider, pitchAdjSlider, yawAdjSlider;
Knob        motor1Knob;

int currentTime, serialTime, updateTime;
int serial_count;
int dt, freq;
float roll, pitch, yaw;
int motor1_speed, az;
float gx, gy, gz, batt;

float Kt=1.3;
float Ka=5.5;
float Kp=32.0;
float Ki=45.0;
float Kd=95.0;
float Kz = 0.0;
float rollAdj=0.0;
float pitchAdj=0.0;
float yawAdj=0.0;

void setup() {
  size(600, 300);
  smooth();
  frameRate(60);

  //serial setup/////////////////////////////////////////////////////////////////////////////////////////////
  myPort = new Serial(this, "COM4", 115200);
  //myPort.buffer(64);
  delay(500);

  //font/////////////////////////////////////////////////////////////////////////////////////////////////////
  String[] fontList = PFont.list();
  printArray(fontList);
  PFont font = createFont("Consolas", 16, true);
  fill(20);
  textAlign(RIGHT);
  textFont(font);
  textSize(17);

  //ControlP5 setup/////////////////////////////////////////////////////////////
  cp5 = new ControlP5(this);
  cp5.setFont(font);
  cp5.addFrameRate().setInterval(10).setColorValueLabel(color(130)) .setPosition(0, height - 20);
  //chart
  dtChart  = cp5.addChart("dt").setPosition(200, 10).setSize(150, 40).setRange(-1, 300).setView(Chart.LINE).setStrokeWeight(5).setColorCaptionLabel(color(10)).setColorBackground(color(230, 230, 230));
  dtChart.addDataSet("freq") .setColors("freq", color(10, 10, 10))   .setData("freq", new float[300]);
  dtChart.addDataSet("0s") .setColors("0s", color(180, 180, 180))   .setData("0s", new float[300]);

  AngleChart  = cp5.addChart("Angle").setPosition(200, 80).setSize(150, 80).setRange(-3, 3).setView(Chart.LINE).setStrokeWeight(5).setColorCaptionLabel(color(10)).setColorBackground(color(230, 230, 230));
  AngleChart.addDataSet("0deg") .setColors("0deg", color(180, 180, 180))   .setData("0deg", new float[300]);
  AngleChart.addDataSet("Roll") .setColors("Roll", color(10, 10, 10))   .setData("Roll", new float[300]);
  AngleChart.addDataSet("Pitch") .setColors("Pitch", color(0, 0, 255))   .setData("Pitch", new float[300]);

  //slider
  KtSlider  = cp5.addSlider("Kt").setPosition(390, 10).setSize(15, 50).setRange(0, 100).setNumberOfTickMarks(1001).snapToTickMarks(true).setValue(Kt).setLock(false) .setColorCaptionLabel(color(10)).setColorBackground(color(230, 230, 230)).setColorForeground(color(180, 180, 180)).setColorActive(color(140, 140, 140))  .setColorValueLabel(color(10, 10, 10)).setFont(createFont("", 12)).setDecimalPrecision(1);
  //cp5.getController("Kt") .getCaptionLabel().align(ControlP5.LEFT_OUTSIDE, ControlP5.LEFT_OUTSIDE).setPaddingX(10);
  KaSlider  = cp5.addSlider("Ka").setPosition(450, 10).setSize(15, 50).setRange(0, 100).setNumberOfTickMarks(1001).snapToTickMarks(true).setValue(Ka).setLock(false) .setColorCaptionLabel(color(10)).setColorBackground(color(230, 230, 230)).setColorForeground(color(180, 180, 180)).setColorActive(color(140, 140, 140))  .setColorValueLabel(color(10, 10, 10)).setFont(createFont("", 12)).setDecimalPrecision(1);
  //cp5.getController("Ka") .getCaptionLabel().align(ControlP5.LEFT_OUTSIDE, ControlP5.LEFT_OUTSIDE).setPaddingX(10);
  KzSlider  = cp5.addSlider("Kz").setPosition(510, 10).setSize(15, 50).setRange(0, 100).setNumberOfTickMarks(1001).snapToTickMarks(true).setValue(Kz).setLock(false) .setColorCaptionLabel(color(10)).setColorBackground(color(230, 230, 230)).setColorForeground(color(180, 180, 180)).setColorActive(color(140, 140, 140))  .setColorValueLabel(color(10, 10, 10)).setFont(createFont("", 12)).setDecimalPrecision(1);
  //cp5.getController("Ka") .getCaptionLabel().align(ControlP5.LEFT_OUTSIDE, ControlP5.LEFT_OUTSIDE).setPaddingX(10);

  KpSlider  = cp5.addSlider("Kp").setPosition(390, 80).setSize(15, 50).setRange(0, 100).setNumberOfTickMarks(101).snapToTickMarks(true).setValue(Kp).setLock(false) .setColorCaptionLabel(color(10)).setColorBackground(color(230, 230, 230)).setColorForeground(color(180, 180, 180)).setColorActive(color(140, 140, 140))  .setColorValueLabel(color(10, 10, 10)).setFont(createFont("", 12)).setDecimalPrecision(1);
  //cp5.getController("Kp") .getCaptionLabel().align(ControlP5.LEFT_OUTSIDE, ControlP5.LEFT_OUTSIDE).setPaddingX(10);
  KiSlider  = cp5.addSlider("Ki").setPosition(450, 80).setSize(15, 50).setRange(0, 100).setNumberOfTickMarks(1001).snapToTickMarks(true).setValue(Ki).setLock(false) .setColorCaptionLabel(color(10)).setColorBackground(color(230, 230, 230)).setColorForeground(color(180, 180, 180)).setColorActive(color(140, 140, 140))  .setColorValueLabel(color(10, 10, 10)).setFont(createFont("", 12)).setDecimalPrecision(1);
  //cp5.getController("Ki") .getCaptionLabel().align(ControlP5.LEFT_OUTSIDE, ControlP5.LEFT_OUTSIDE).setPaddingX(10);
  KdSlider  = cp5.addSlider("Kd").setPosition(510, 80).setSize(15, 50).setRange(0, 300).setNumberOfTickMarks(3001).snapToTickMarks(true).setValue(Kd).setLock(false) .setColorCaptionLabel(color(10)).setColorBackground(color(230, 230, 230)).setColorForeground(color(180, 180, 180)).setColorActive(color(140, 140, 140))  .setColorValueLabel(color(10, 10, 10)).setFont(createFont("", 12)).setDecimalPrecision(1);
  //cp5.getController("Kd") .getCaptionLabel().align(ControlP5.LEFT_OUTSIDE, ControlP5.LEFT_OUTSIDE).setPaddingX(10);
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

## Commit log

2026-04-05 🚀 3軸姿勢制御モジュール: 初期構築
    - 理論ドキュメント（物理数式・PID制御・モーターミキシング）
    - 完全な部品表（BOM）: Nidec 24H055M020 モーター特定済み
    - 回路図・ピン配線表
    - 実験スケジュール・工程表
    - ファームウェア（Pico W / ESP32）
    - PCBガーバーデータ
    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
    [copper_bottom.gbr, copper_top.gbr, drill_1_16.xln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]
2026-04-05 📖 ソフトウェアセットアップガイド追加
    - Arduino IDE セットアップ手順（Pico W / ESP32）
    - Processing IDE セットアップ手順（PIDチューニングGUI）
    - トラブルシューティング表
2026-04-05 📚 理論ドキュメント大幅拡充
    - 学問分野マップ追加（物理学・数学・制御工学・電気電子・情報・機械工学）
    - 各分野がプロジェクトでどう使われるか詳細解説
    - 身近な例との比較（自転車・スケーター・人工衛星）
    - 安定/不安定平衡の直感的説明
    - PID制御の車の運転での例え
    - 相補フィルタの直感的解説
    - 各数式への補足コメント（📝）追加
    - GitHub数式レンダリング互換性修正（_エスケープ、boxed削除）
2026-04-05 📖 組立手順・PIDチューニングガイド追加
    - docs/05_assembly.md: Step 1〜5の組立手順、工具リスト、チェックリスト
    - docs/06_tuning.md: PIDパラメータ解説、段階的チューニング手順、トラブルシューティング表
2026-04-05 🛒 BOMに具体的な購入リンク・チェックリスト追加
    - 全部品の具体的なAmazon/秋月電子/AliExpress購入リンク
    - 優先度順のお買い物チェックリスト（コピペで使える）
    - NJM7805FA型番、Pico W価格など最新情報に更新
2026-04-05 🌐 英語版ドキュメント追加 / Add English documentation
    - README_en.md: Full English README with Getting Started reading order guide
    - docs/01_theory_en.md: Complete English translation of physics theory
    - docs/02_bom_en.md: Complete English translation of BOM with purchase links
    - README.md: Added link to English version
2026-04-06 📝 部品発注完了ログを追記（2026-04-06）
    - 全部品の発注先・型番・数量・価格を記録
    - AliExpress, JLCPCB, Amazon, 秋月電子で発注完了
    - Next Action（検品→環境構築→組立→チューニング）を追記
2026-04-06 🔧 ドキュメント・コードの不備修正
    - docs/02_bom.md, 02_bom_en.md: モーター種別を「ブラシ付きDC」→「ドライバ内蔵BLDC」に修正（詳細セクションと一致）
    - docs/01_theory.md, 01_theory_en.md: セクション番号の重複修正（2→3: 3次元倒立振子モデル）
    - docs/04_software_setup.md: SerialBT.hライブラリの要件を明確化（「不要」と矛盾していた記述を修正）
    - docs/02_bom.md: STL/STEPファイルが本リポジトリに未収録である旨の注記を追加
    - docs/02_bom.md, schedule.md: ハードコードされたWindowsパス（D:\...）をリポジトリ相対パスに修正
    - processing/tuning_gui.p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
    [3axis_control.ino, tuning_gui.pde]
